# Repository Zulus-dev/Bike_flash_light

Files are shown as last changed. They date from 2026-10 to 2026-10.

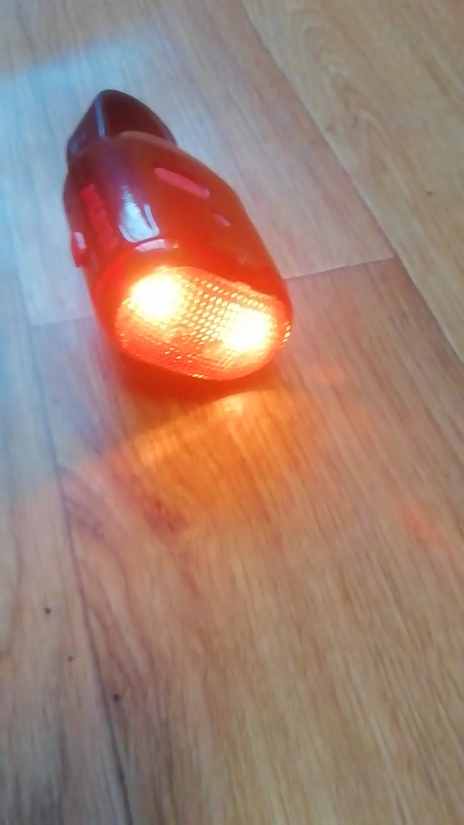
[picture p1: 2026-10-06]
images/VID_20261006_160003_exported_4752.jpg

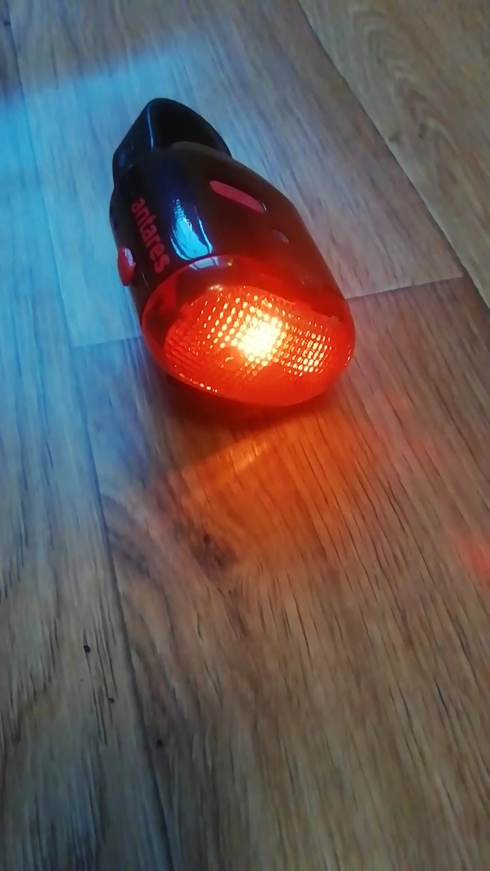
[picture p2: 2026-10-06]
images/VID_20261006_160003_exported_5719.jpg

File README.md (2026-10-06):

20261006_161844-COLLAGE
20261006_161900-ANIMATION
[Описание_веб_интерфейса_Bike_Light.md](https://github.com/user-attachments/files/33128371/_._._Bike_Light.md)

# Умный габарит-поворотник-стоп-сигнал для велосипеда  
**Полное техническое описание проекта (редакция 3.0)**

---

## 0. Инструменты разработки

| Инструмент | Назначение |
|---|---|
| **Blender** | 3D-моделирование корпуса / визуализация |
| **KiCad 9** | Схема и печатная плата |
| **VS Code + PlatformIO**| Прошивка (ESP-IDF framework) |

Сборка: PlatformIO, board `esp32-c3-devkitm-1`, framework `espidf`, flash 4 МБ, таблица разделов `partitions_ota.csv` (OTA).

---

## 1. Цель проекта

Создать устройство, которое:

- Работает от литиевого аккумулятора 18650 с BMS-платой, выдающей стабильные **+5 В**.
- Управляет каналами: **LED_LEFT**, **LED_CENTER**, **LED_RIGHT**, **LED_STRIP**, **LASER** + зуммер через **ULN2003A**.
- Мониторинг батареи (сглаженный) и **фоторезистор GL5528** в веб-UI.
- Функции: габарит (дыхание), стоп, поворотник, аварийка, охрана, автоаварийка, эффекты вкл/выкл.
- WiFi SoftAP для настройки, мониторинга и **OTA-обновления прошивки**.

---

## 2. Полный список компонентов

| Обозначение | Наименование | Параметры / корпус | Кол-во | Назначение |
|---|---|---|---|---|
| U1 | ESP32-C3 SuperMini | ESP32-C3FN4, 4 МБ Flash, USB-C | 1 | Контроллер |
| U2 | MPU-6050 (GY-521) | I2C, 3.3 В | 1 | Наклон и ускорение |
| U3 | ULN2003A | DIP-16 / SOIC-16 | 1 | Драйвер LED и зуммера |
| Q1 | AO3401A | P-MOSFET, SOT-23 | 1 | Ключ питания |
| Q2 | AO3400A | N-MOSFET, SOT-23 | 1 | POWER_HOLD |
| D1 | BMS 1S 5V | Защита + boost 5 В | 1 | Питание |
| D2…D6 | IR204A / LED | 3 мм | 5 | RIGHT, CENTER, LEFT, LASER, STRIP |
| R1–R5 | Резисторы | 120 Ом | 5 | Токоограничение LED/зуммера |
| R6 | Резистор | 100 кОм | 1 | Подтяжка G Q1 к +5 В |
| R7 | Резистор | 1 кОм | 1 | SW1 → G Q1 |
| R8 | Резистор | 100 кОм | 1 | Подтяжка G Q2 к GND |
| R9 | Резистор | 1 кОм | 1 | GPIO21 → G Q2 |
| R10, R11 | Резисторы | 100 кОм | 2 | Делитель батареи 1:2 |
| R12 | Резистор | 10 кОм | 1 | Делитель LDR |
| C2, C3, C6, C7 | Конденсаторы | 150 нФ | 4 | Развязка / фильтр АЦП |
| C8 | Конденсатор | 100 нФ | 1 | Фильтр LDR у GPIO0 |
| C4, C5 | Конденсаторы | 47 мкФ | 2 | Фильтр питания |
| SW1 | Кнопка | 6×6 мм | 1 | Включение питания |
| SW2 | Кнопка | 6×6 мм | 1 | Режимы / WiFi / выключение |
| BZ2 | Buzzer | 12×9.5 мм | 1 | Звук |
| BT1 | Аккумулятор | 18650 | 1 | Источник питания |
| LDR1 | GL5528 | Фоторезистор 5 мм | 1 | Освещённость |

---

## 3. Описание цепей и соединений

### 3.1. Силовая часть

- **BAT+** → вход BMS (BAT+).
- Выход BMS **5V+** → исток (S) Q1 (AO3401A).
- Затвор (G) Q1: R6 к 5V+, R7 к SW1 на GND, сток Q2.
- Сток (D) Q1 = шина **+5V**.
- Q2 (AO3400A): S → GND; G через R9 ← **GPIO21** (POWER_HOLD); R8 подтяжка G к GND.

### 3.2. Питание 3.3 В

Встроенный LDO ESP32-C3 SuperMini. **3V3** → MPU-6050 и делитель LDR (R12 + LDR1).

### 3.3. Светодиоды и зуммер (ULN2003A)

Аноды LED от +5V через 120 Ом; катоды на открытые коллекторы ULN.  
COM ULN → +5V, GND ULN → общая земля.

| Канал ULN | Вход | GPIO | Нагрузка |
|---|---|---|---|
| 1 | I1 | GPIO5 | Зуммер |
| 2 | I2 | GPIO4 | LED_RIGHT |
| 3 | I3 | GPIO3 | LED_CENTER |
| 4 | I4 | **GPIO2** | **LED_LEFT** (поворотник) |
| 5 | I5 | GPIO7 | LASER |
| 6 | I6 | **GPIO20**| **LED_STRIP** |
| 7 | I7 | — | не используется |

> LED_STRIP на **GPIO20** (не GPIO8). GPIO8 свободен — strapping для USB download.

### 3.4. Мониторинг батареи

```
BAT+ ── R11 100к ──●── GPIO1 (ADC1_CH1)
                   │
                  R10 100к
                   │
                  GND  +  C6 150нФ
```

Делитель 1:2. Замер раз в **3 с**, EMA + среднее за окно **~60 с** (UI без скачков от ШИМ/вибрации).

### 3.5. Фоторезистор GL5528

```
+3.3V ── R12 10к ──●── GPIO0 (ADC1_CH0)
                   │
                LDR1 GL5528
                   │
                  GND  +  C8 100нФ
```

Светло → `ldr_percent` → 0; темно → 100. Общий `ADC_UNIT_1` (`adc1_shared`) для батареи и LDR.

### 3.6. Кнопки и MPU-6050

- SW1 → через R7 на затвор Q1.
- SW2 → GPIO6.
- MPU-6050: SDA = GPIO9, SCL = GPIO10, AD0 = GND, VCC = 3V3.

### 3.7. Сводная таблица GPIO

| GPIO | Назначение | Примечание |
|---|---|---|
| GPIO0 | LDR (АЦП) | ADC1_CH0 |
| GPIO1 | Батарея (АЦП)| ADC1_CH1 |
| **GPIO2** | **LED_LEFT**  | Поворотник |
| GPIO3 | LED_CENTER | |
| GPIO4 | LED_RIGHT | |
| GPIO5 | BUZZER | |
| GPIO6 | BUTTON_MODE | |
| GPIO7 | LASER | |
| **GPIO8** | **свободен**  | Strapping — не нагружать ULN |
| GPIO9 | I2C_SDA | Strapping |
| GPIO10 | I2C_SCL | |
| **GPIO20**| **LED_STRIP** | |
| GPIO21 | POWER_HOLD | |

### 3.8. Прошивка по USB

Без снятия ULN (GPIO8 свободен).  
Принудительный download: BOOT (GPIO9) + RESET.

```bash
pio run -t upload
pio device monitor
```

### 3.9. OTA — обновление прошивки по Wi‑Fi

Таблица разделов: **`partitions_ota.csv`**

| Раздел | Размер (примерно) |
|---|---|
| ota_0 | ~1,75 МБ |
| ota_1 | ~1,75 МБ |

Типичный размер `firmware.bin`: **~0,9–1,2 МБ** — помещается в слот.

**Первый раз** после смены partition table — только USB. Дальше можно только по Wi‑Fi.

#### Где взять файл прошивки

После сборки:

```bash
pio run
```

Файл:

```
.pio/build/esp32c3_supermini/firmware.bin
```

Полный путь (Windows, пример):

```
C:\...\bike_light_esp_idf\.pio\build\esp32c3_supermini\firmware.bin
```

Нужен именно **`.bin`**, не `.elf`.

#### Как прошить по Wi‑Fi

1. Включить устройство, удержать **SW_MODE ≥ 8 с** → SoftAP.
2. Телефон/ПК: сеть **`BikeLight_AP`**, пароль **`12345678`**.
3. Браузер: **http://192.168.4.1**
4. Секция **WiFi** → видна версия прошивки → выбрать `firmware.bin` → **Загрузить прошивку**.
5. Дождаться 100 % и сообщения об OK — устройство **перезагрузится само**.

API: `POST /api/ota`, тело = сырой binary, `Content-Type: application/octet-stream`.

При обрыве загрузки boot остаётся на старом слоте (безопасный откат).

---

## 4. Принцип работы

- **Габарит** — дыхание LEFT / CENTER / RIGHT; лента и лазер по режимам и LDR.
- **Стоп** — динамическое ускорение (Δg по X/Y относительно медленной базы) + опционально наклон pitch; защита от кочек; подтверждение по времени.
- **Поворотник** — удержание бокового roll ≥ мин. угла; **приоритет над стопом** после старта; max по умолчанию 90°.
- **Аварийка / охрана / автоаварийка** — без изменений по смыслу.

### Стоп (параметры после полевых испытаний)

| Параметр | Поле config | Default | Смысл |
|---|---|---|---|
| Порог торможения | `brake_decel_threshold` | 0.45 g | Порог динамического Δg |
| Защита от кочек | `brake_bump_reject` | 5 (1–10) | Жёсткость отсева ударов |
| Подтверждение | `brake_confirm_sec` | 0.08 с | Сколько держать условие |
| Наклон (спуск) | `brake_pitch_deg` | 0 (выкл) | \|pitch\| ≥ порога; 0 = выкл |
| Длительность стопа | `brake_active_time_sec` | 1.5 с | Сколько мигать после события |

Алгоритм: `mag(filtered − slow_base)` по осям X/Y ≥ порога → candidate → confirm → стоп.  
Pitch-стоп **не** срабатывает при сильном боковом наклоне (не мешает поворотнику).

### Поворотник

| Параметр | Default |
|---|---|
| Мин. угол | 18° |
| Макс. угол | 90° |
| Удержание | 0.8 с |
| Время сигнала | 8 с |

Инверсия сторон — один раз (флаг `invert_turn_signals`), без двойного переворота в state machine.

### Режимы ленты / лазера

Без изменений: `strip_mode` (off / always / dark_only / scale), `laser_mode` (off / always / dark_only / brake_only_dark).

---

## 5. Кнопка SW_MODE

| Удержание | Действие |
|---|---|
| < 1 с | Обычный ↔ Аварийный |
| 2–4 с | Выключение питания |
| 4–8 с | Постановка / снятие охраны |
| ≥ 8 с | WiFi SoftAP вкл/выкл |

---

## 6. WiFi и веб-интерфейс

- SoftAP: `BikeLight_AP` / `12345678` → http://192.168.4.1  
- API: `/api/config`, `/api/status`, `/api/command`, **`/api/ota`**  
- Статус: режим, охрана, батарея (сглаженная), roll/pitch, LDR, **версия прошивки**  
- Секция WiFi: SSID, пароль, канал, таймаут, **загрузка OTA**  
- Секция Стоп: порог, мигание, длительность, яркость, **защита от кочек**, **подтверждение**, **наклон спуска**  
- NVS (`bike_config_t`); при смене размера структуры — defaults  

Подробности UI: `Описание_веб_интерфейса_Bike_Light.md` (в корне artifacts).

---

## 7. Архитектура прошивки

| Модуль | Назначение |
|---|---|
| adc1_shared | Один ADC_UNIT_1 |
| battery | АЦП 3 с, EMA, среднее ~60 с |
| ldr | percent, is_dark, гистерезис |
| config | NVS, defaults |
| led_control | ШИМ 5 каналов |
| buzzer | Тон, мелодии, сирена |
| motion_sensor | MPU-6050, LPF, Δg-тормоз, tilt |
| button | Антидребезг |
| state_machine | Режимы, приоритет поворот/стоп |
| effects | Вкл/выкл/охрана |
| wifi_web | SoftAP, HTTP, UI, **OTA** |
| main | Init, цикл ~50 Гц |

Пины в `config.h` (2.6): LED_LEFT=2, LED_STRIP=20, LASER=7, POWER_HOLD=21, LDR=0, BAT=1.

---

## 8. Инструкция пользователя

1. **Включение** — SW_POWER, эффект, габарит.  
2. **Езда** — дыхание; стоп и поворотники по датчику; лента/лазер по LDR.  
3. **Аварийка** — короткое SW_MODE.  
4. **Выключение** — 2–4 с.  
5. **Охрана** — 4–8 с.  
6. **Настройки / OTA** — ≥ 8 с, WiFi, браузер 192.168.4.1.

Рекомендуемые настройки после установки на раму (веб-UI → Сохранить):

| Параметр | Старт |
|---|---|
| Порог торможения | 0.35–0.50 |
| Подтверждение | 0.06–0.10 с |
| Защита от кочек | 4–6 |
| Мин. угол поворота | 15–20° |
| Макс. угол | 90° |
| Удержание поворота | 0.5–1.0 с |
| Наклон спуска | 0, пока не отладите |

---

## 9. Заключение (актуально на 2.6 + OTA)

- GPIO: LED_LEFT=2, LED_STRIP=20, GPIO8 свободен, POWER_HOLD=21.  
- Стоп: динамическое Δg, защита от кочек, confirm, опциональный pitch.  
- Поворотник: приоритет над стопом, hold ~0.8 с, max 90°.  
- Батарея: редкий замер + минутное среднее в UI.  
- **OTA по Wi‑Fi**: `partitions_ota.csv`, `POST /api/ota`, файл `.pio/build/esp32c3_supermini/firmware.bin`.  
- Стек: Blender, KiCad 9, VS Code + PlatformIO (ESP-IDF).

Устройство готово к сборке, прошивке (USB / OTA) и использованию.

[Описание_проекта_Bike_Light_v3.0.md](https://github.com/user-attachments/files/33128378/_._Bike_Light_v3.0.md)

# Веб-интерфейс Bike Light (ANTARES) — описание всех функций

**Редакция прошивки:** 3.0 (+ OTA, доработка стоп/поворот/батарея)  
**Точка доступа:** `BikeLight_AP` / `12345678`  
**Адрес:** http://192.168.4.1  
**Файл UI:** `bike_light_esp_idf/src/wifi_web.c`  
**Макет в проекте:** `imS7H.jpg` (концепт)

---

## 1. Общий вид и навигация

Заголовок: **ANTARES Bike Light**.

### Статус-бар (`/api/status`, ~0.8 с)

| Поле | Описание |
|---|---|
| Режим | NORMAL / HAZARD / ALARM |
| Охрана | `норма` / `охрана` / `ТРЕВОГА` |
| Батарея | % и вольты (**сглаженное среднее ~1 мин**, без скачков) |
| Roll / Pitch | Углы MPU-6050 |
| Acc | Суммарное ускорение |
| LDR | Темно/Светло, %, raw |
| Версия ПО | `fw_version` / `fw_date` (в секции WiFi) |

### Макеты (`ui_theme`)

| # | Имя | Поведение |
|---|-----|---|
| 0 | classic | Раскрывающиеся секции |
| 1 | hud | Карусель карточек |
| 2 | tiles | Сетка плиток (по умолчанию) |
| 3 | orbit | Иконки + панели |

### Стили иконок (`ui_icon_style`)

0 = soft · 1 = bold · 2 = duo (везде есть иконка LDR).

### API

| Метод | Путь | Назначение |
|---|---|---|
| GET | `/` | HTML |
| GET/POST | `/api/config` | Настройки ↔ NVS |
| GET | `/api/status` | Живой статус + версия прошивки |
| POST | `/api/command` | arm, disarm, calibrate, reboot, poweroff, melody_preview |
| **POST** | **`/api/ota`** | **Загрузка firmware.bin (сырое тело)** |

---

## 2. Секции настроек

### Управление (`ctrl`)

| Кнопка | Действие |
|---|---|
| На охрану / Снять | MODE_ALARM |
| Калибровка | MPU offsets → NVS |
| Ребут | `esp_restart` |
| Выключить | POWER_HOLD off |

### Габарит (`breath`)

Период дыхания, яркость крайних, яркость центра.

### Стоп (`brake`) — актуально после полевых испытаний

| Параметр | ID UI | Описание |
|---|---|---|
| Порог торможения | `brake` | Динамическое Δg (не сырой ax). Рекомендуется 0.35–0.50 |
| Период мигания | `bper` | |
| Длительность стопа | `bact` | Сколько мигать после события |
| Яркость стопа | `bbr` | |
| **Защита от кочек** | `bbump` | 1–10 (выше = жёстче отсев ударов) |
| **Подтверждение тормоза** | `bconf` | 0.04–0.40 с удержания условия |
| **Наклон вперёд (спуск)** | `bpitch` | 0–45°; **0 = выкл**. Срабатывает по \|pitch\| |

Стоп по pitch **не** активен при сильном боковом наклоне (чтобы не мешать поворотнику).

### Поворот (`turn`)

| Параметр | Рекомендация |
|---|---|
| Мин. угол | 15–20° |
| Макс. угол | **90°** (не ставить 60 — сильный наклон иначе «выключает» поворот) |
| Удержание | **0.5–1.0 с** |
| Время сигнала | 8 с |
| Инверсия сторон | если лево/право перепутаны |

После удержания наклона **поворотник имеет приоритет** над стопом.

### Авто / Охрана / LDR / Лазер / Лента / Эффекты / Звук

Без смены смысла относительно 2.6 (автоаварийка, пороги охраны, LDR, режимы laser/strip, мелодии).

### WiFi (`wifi`) + **OTA**

| Элемент | Описание |
|---|---|
| SSID / Пароль / Канал / Таймаут | Параметры SoftAP |
| **Версия прошивки** | Из `esp_app_get_description()` |
| **Файл .bin** | Выбор файла на телефоне/ПК |
| **Загрузить прошивку** | `POST /api/ota`, прогресс-бар |

---

## 3. Инструкция: прошивка по Wi‑Fi (OTA)

### 3.1. Получить файл прошивки на компьютере

В каталоге проекта PlatformIO:

```bash
pio run
```

Готовый файл:

```
bike_light_esp_idf/.pio/build/esp32c3_supermini/firmware.bin
```

Примеры полного пути:

- **Windows:** `C:\Users\<имя>\...\bike_light_esp_idf\.pio\build\esp32c3_supermini\firmware.bin`
- **Linux/macOS:** `.../bike_light_esp_idf/.pio/build/esp32c3_supermini/firmware.bin`

Только **`firmware.bin`**. Файлы `.elf` / `.map` для OTA не подходят.

Размер обычно **~0,9–1,2 МБ**; слот OTA ~1,75 МБ — запас есть.

Скопируйте `.bin` на телефон (облако, USB, мессенджер) или откройте UI с того же ПК, где лежит файл.

### 3.2. Первый раз после смены таблицы разделов

Если на плате ещё **не** была прошивка с `partitions_ota.csv`:

```bash
pio run -t upload
```

Только по **USB**. Дальше можно обновлять по Wi‑Fi.

### 3.3. Загрузка по Wi‑Fi

1. Питание устройства включено.  
2. Удержать **кнопку режимов ≥ 8 секунд** → SoftAP.  
3. Подключиться к Wi‑Fi **`BikeLight_AP`**, пароль **`12345678`**.  
4. Браузер: **http://192.168.4.1**  
5. Открыть секцию **WiFi**.  
6. Убедиться, что видна текущая **версия**.  
7. **Выбрать файл** → указать `firmware.bin`.  
8. Нажать **«Загрузить прошивку»**.  
9. Дождаться прогресса 100 % и «OK — перезагрузка…».  
10. Устройство перезапустится само; через ~10–20 с снова можно подключиться к AP (если SoftAP включите повторно).

Не выключайте питание и не отходите от AP во время загрузки.

### 3.4. Если OTA не прошла

- Проверьте, что файл именно `.bin` и размер > 50 КБ.  
- Перезапустите SoftAP (≥ 8 с).  
- При необходимости прошейте по USB: `pio run -t upload`.  
- При обрыве обычно остаётся **старая** рабочая прошивка (второй слот не активируется).

---

## 4. Связь с железом

- LDR GPIO0, батарея GPIO1, LED_LEFT GPIO2, LED_STRIP GPIO20, LASER GPIO7, POWER_HOLD GPIO21.  
- SoftAP только пока включён кнопкой (≥ 8 с) или из охраны.  
- Настройки → NVS; смена размера `bike_config_t` сбрасывает на defaults — после крупного обновления заново **Сохранить** нужные слайдеры.

---

## 5. Файлы в проекте

| Путь | Назначение |
|---|---|
| `Описание_веб_интерфейса_Bike_Light.md` | Этот документ |
| `bike_light_esp_idf/Описание_проекта_Bike_Light_v3.0.md` | Полное ТО проекта |
| `bike_light_esp_idf/src/wifi_web.c` | HTML + API + OTA |
| `bike_light_esp_idf/partitions_ota.csv` | Два OTA-слота |
| `.pio/build/esp32c3_supermini/firmware.bin` | Файл для USB и OTA (после `pio run`) |

---

*Соответствует прошивке 3.0 с OTA, динамическим стопом, приоритетом поворотника и сглаженной батареей.*

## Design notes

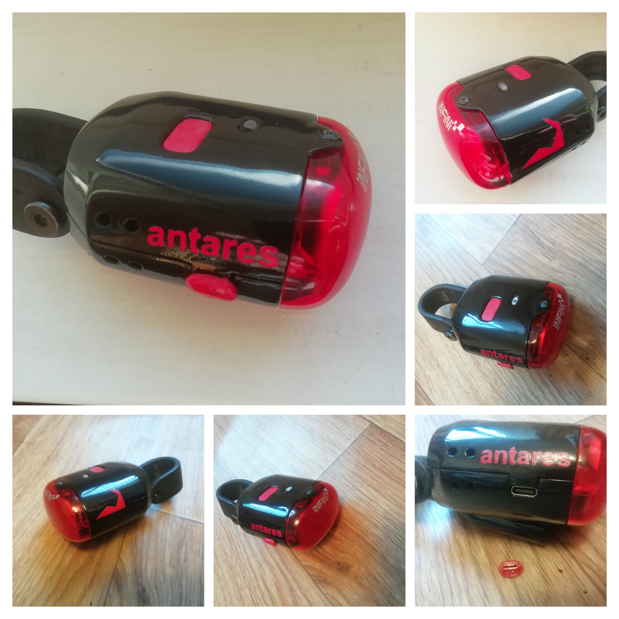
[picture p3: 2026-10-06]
images/20261006_161844-COLLAGE.jpg

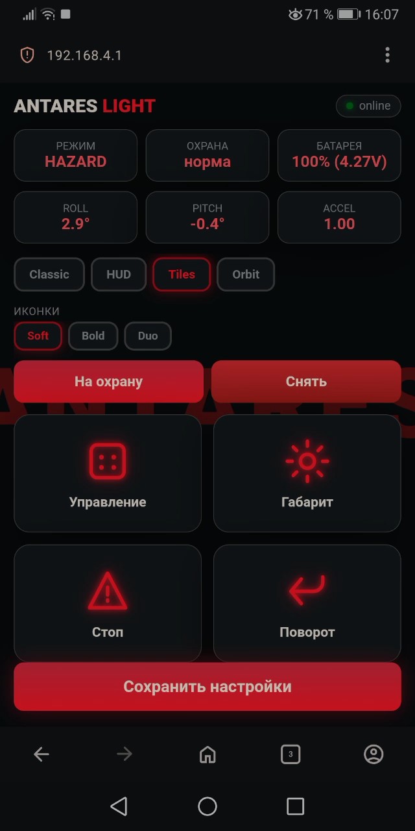
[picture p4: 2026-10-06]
images/SVID_20261006_160615_1_exported_90806.jpg

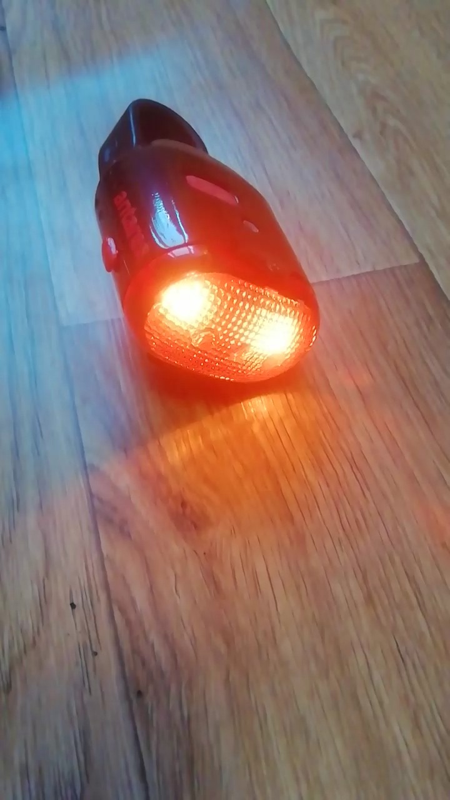
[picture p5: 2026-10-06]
images/VID_20261006_160003_exported_6387.jpg

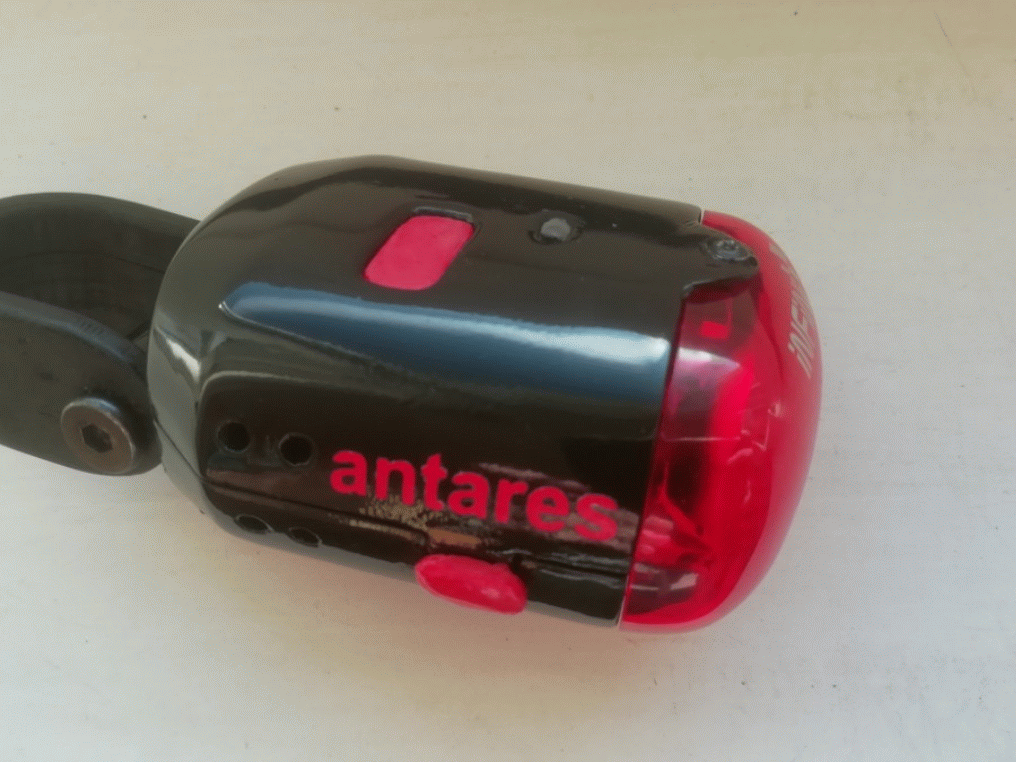
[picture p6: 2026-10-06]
images/20261006_161900-ANIMATION.gif

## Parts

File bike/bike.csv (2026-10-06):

Reference | Qty | Value | DNP | Exclude from BOM | Exclude from Board | Footprint | Datasheet
BT1 | 1 | Battery_Cell |  |  |  | Battery:BatteryHolder_MPD_BH-18650-PC | ~
BZ2 | 1 | Buzzer |  |  |  | Buzzer_Beeper:Buzzer_12x9.5RM7.6 | ~
C1,C2,C3 | 3 | 150nF |  |  |  | Capacitor_SMD:C_0805_2012Metric_Pad1.18x1.45mm_HandSolder | ~
C4,C5 | 2 | 10mF |  |  |  | Capacitor_THT:CP_Radial_D5.0mm_P2.00mm | ~
D1,D2,D3,D4,D5,D6 | 6 | IR204A |  |  |  | LED_THT:LED_D3.0mm_IRBlack | http://www.everlight.com/file/ProductFile/IR204-A.pdf
D7 | 1 | ~ |  |  |  | BMS_1S_5V:BMS_1S_5V
Q1 | 1 | AO3401A |  |  |  | Package_TO_SOT_SMD:SOT-23 | http://www.aosmd.com/pdfs/datasheet/AO3401A.pdf
Q2 | 1 | S9014 |  |  |  | Package_TO_SOT_THT:TO-92_Inline | http://www.unisonic.com.tw/datasheet/S8050.pdf
Q3,Q4,Q5,Q6 | 4 | S8050 |  |  |  | Package_TO_SOT_THT:TO-92_Inline | http://www.unisonic.com.tw/datasheet/S8050.pdf
R1,R2,R3 | 3 | 47 Om |  |  |  | Resistor_SMD:R_1206_3216Metric_Pad1.30x1.75mm_HandSolder | ~
R4,R5,R6,R7,R8,R9 | 6 | 1 kOm |  |  |  | Resistor_SMD:R_1206_3216Metric_Pad1.30x1.75mm_HandSolder | ~
R10 | 1 | 100 kOm |  |  |  | Resistor_SMD:R_1206_3216Metric_Pad1.30x1.75mm_HandSolder | ~
SW1 | 1 | SW_Power |  |  |  | Button_Switch_SMD:SW_SPST_Omron_B3FS-101xP | ~
SW2 | 1 | SW_mode |  |  |  | Button_Switch_SMD:SW_SPST_Omron_B3FS-101xP | ~
U1 | 1 | STM32F401CCUx |  |  |  | myelin-kicad:stm32f103c8t6-module-china | https://www.st.com/resource/en/datasheet/stm32f401cc.pdf
U2 | 1 | MPU-6050 |  |  |  | Sensor_Motion:InvenSense_QFN-24_4x4mm_P0.5mm | https://invensense.tdk.com/wp-content/uploads/2015/02/MPU-6000-Datasheet1.pdf
U3 | 1 | AMS1117-3.3 |  |  |  | Package_TO_SOT_SMD:SOT-223-3_TabPin2 | http://www.advanced-monolithic.com/pdf/ds1117.pdf

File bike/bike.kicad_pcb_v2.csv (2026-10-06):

Reference | Qty | Value | DNP | Exclude from BOM | Exclude from Board | Footprint | Datasheet
BT1 | 1 | Battery_Cell |  |  |  | Battery:Battery_Panasonic_CR1025-VSK_Vertical_CircularHoles | ~
BZ2 | 1 | Buzzer |  |  |  | Buzzer_Beeper:Buzzer_12x9.5RM7.6 | ~
C1,C2,C3,C6,C7 | 5 | 150nF |  |  |  | Capacitor_SMD:C_0805_2012Metric_Pad1.18x1.45mm_HandSolder | ~
C4 | 1 | 470 мкФ |  |  |  | Capacitor_THT:CP_Radial_D5.0mm_P2.00mm | ~
C5 | 1 | 47 mF |  |  |  | Capacitor_THT:CP_Radial_D5.0mm_P2.00mm | ~
D1 | 1 | ~ |  |  |  | BMS_1S_5V:BMS_1S_5V
D2 | 1 | IR204A_LED_RIGHT |  |  |  | LED_THT:LED_D3.0mm_IRBlack | http://www.everlight.com/file/ProductFile/IR204-A.pdf
D3 | 1 | IR204A_LED_CENTER |  |  |  | LED_THT:LED_D3.0mm_IRBlack | http://www.everlight.com/file/ProductFile/IR204-A.pdf
D4 | 1 | IR204A_LED_LEFT |  |  |  | LED_THT:LED_D3.0mm_IRBlack | http://www.everlight.com/file/ProductFile/IR204-A.pdf
D5 | 1 | IR204A_Laser |  |  |  | LED_THT:LED_D3.0mm_IRBlack | http://www.everlight.com/file/ProductFile/IR204-A.pdf
D6 | 1 | IR204A_Led_Strip |  |  |  | LED_THT:LED_D3.0mm_IRBlack | http://www.everlight.com/file/ProductFile/IR204-A.pdf
Q1 | 1 | AO3401A |  |  |  | Package_TO_SOT_SMD:SOT-23 | http://www.aosmd.com/pdfs/datasheet/AO3401A.pdf
Q2 | 1 | AO3400A |  |  |  | Package_TO_SOT_SMD:SOT-23_Handsoldering | http://www.aosmd.com/pdfs/datasheet/AO3400A.pdf
R1,R2,R3,R4,R5 | 5 | 100 Om |  |  |  | Resistor_SMD:R_1206_3216Metric_Pad1.30x1.75mm_HandSolder | ~
R6,R8,R10,R11 | 4 | 100 kOm |  |  |  | Resistor_SMD:R_1206_3216Metric_Pad1.30x1.75mm_HandSolder | ~
R7,R9 | 2 | 1 kOm |  |  |  | Resistor_SMD:R_1206_3216Metric_Pad1.30x1.75mm_HandSolder | ~
R12 | 1 | R_Photo |  |  |  | OptoDevice:R_LDR_4.9x4.2mm_P2.54mm_Vertical | ~
R13 | 1 | 10 кOm |  |  |  | Resistor_SMD:R_1206_3216Metric_Pad1.30x1.75mm_HandSolder | ~
SW1 | 1 | SW_Power |  |  |  | Button_Switch_SMD:SW_SPST_Omron_B3FS-101xP | ~
SW2 | 1 | SW_mode |  |  |  | Button_Switch_SMD:SW_SPST_Omron_B3FS-101xP | ~
U1 | 1 | ~ |  |  |  | ESP32-C3-SuperMini:ESP32-C3-SuperMini
U2 | 1 | OC09600 |  |  |  | OC09600:MODULE_OC09600
U3 | 1 | ULN2003A |  |  |  | Package_DIP:DIP-16_W7.62mm_LongPads | http://www.ti.com/lit/ds/symlink/uln2003a.pdf

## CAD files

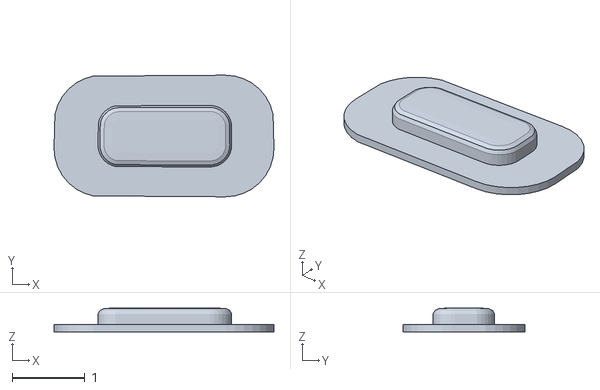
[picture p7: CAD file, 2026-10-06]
flash_box_cap_button.stl
3.03 x 1.68 x 0.327

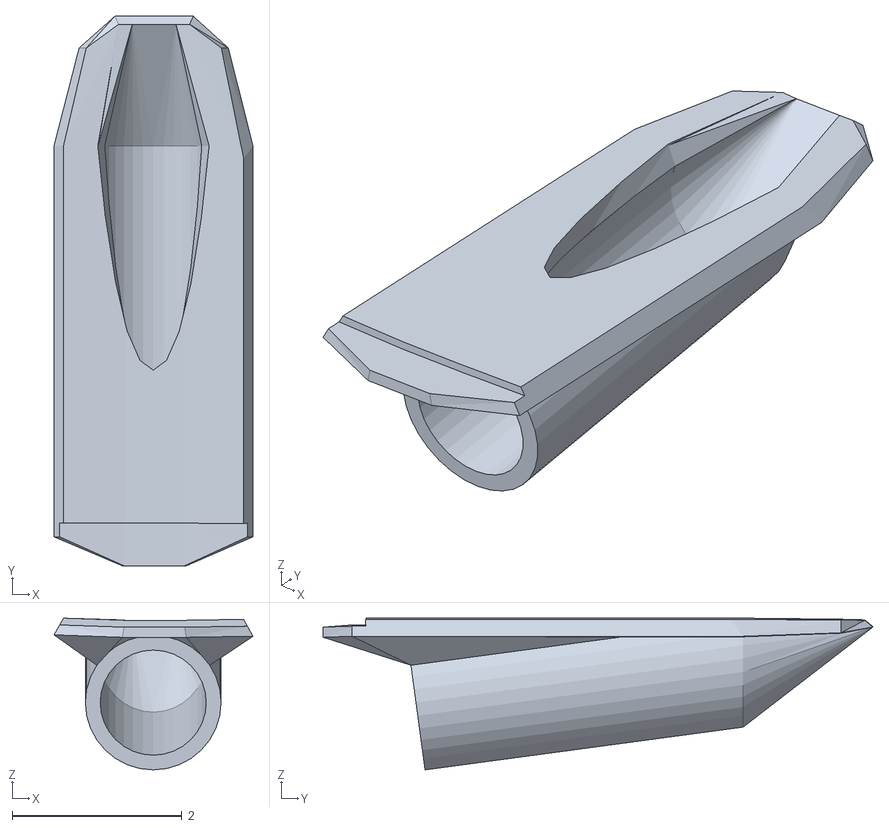
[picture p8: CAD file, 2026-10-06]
flash_box_laser.stl
2.35 x 6.48 x 1.79

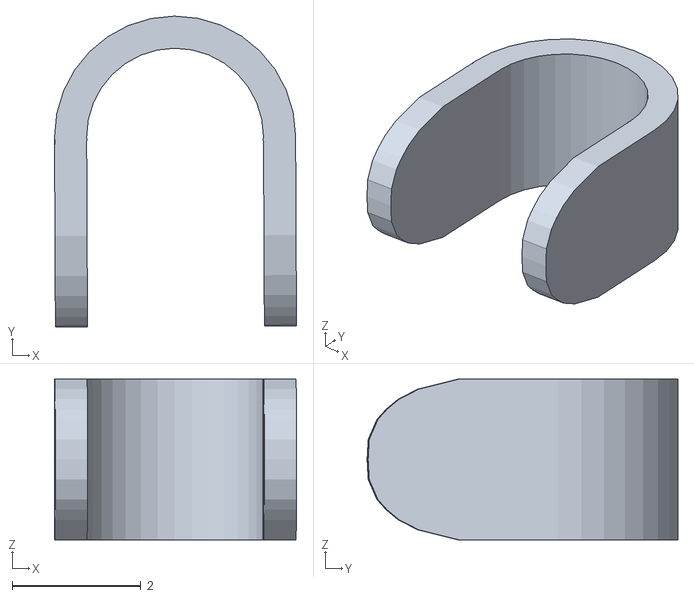
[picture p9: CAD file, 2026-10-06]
flash_box1.stl
3.76 x 4.83 x 2.50

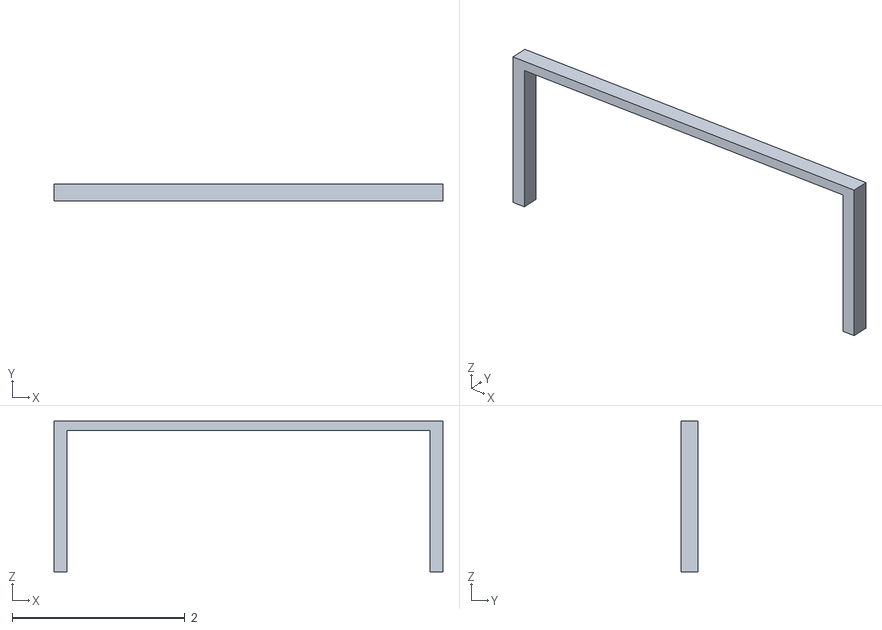
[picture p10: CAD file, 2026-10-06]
flash_box_mount.stl
4.50 x 0.2 x 1.75

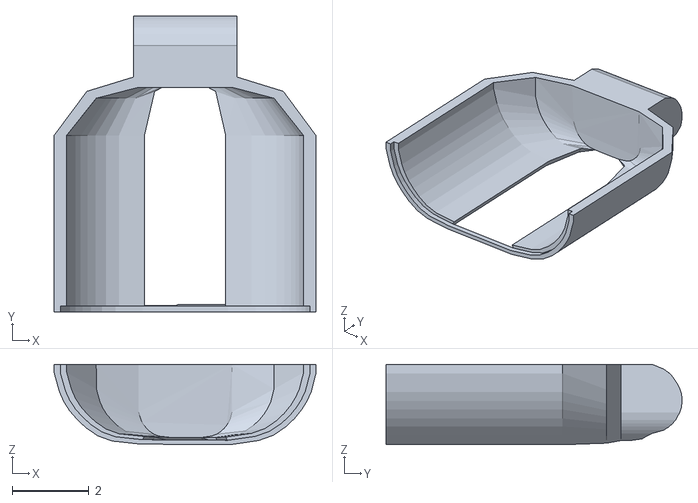
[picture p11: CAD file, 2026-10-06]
flash_box_down.stl
6.84 x 7.73 x 2.10

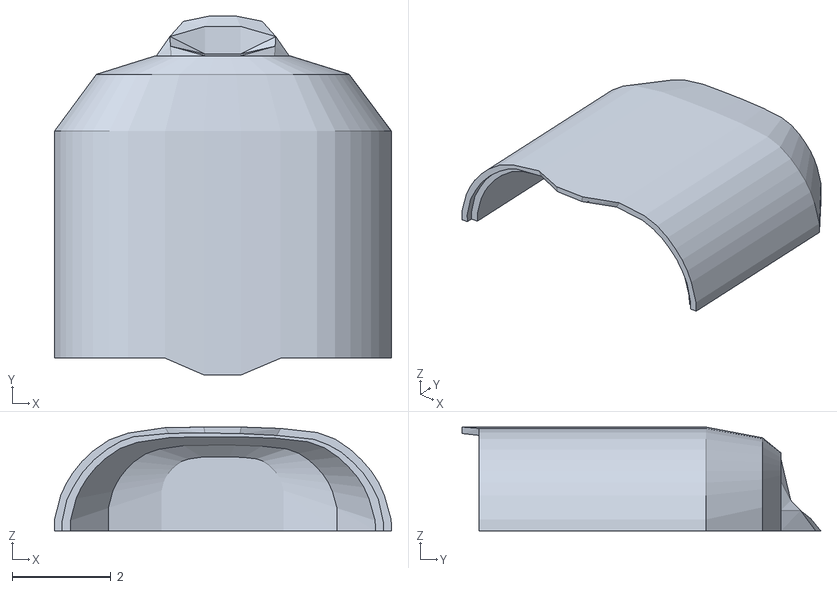
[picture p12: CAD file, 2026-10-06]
flash_box_up.stl
6.84 x 7.29 x 2.11

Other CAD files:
flash_box.blend

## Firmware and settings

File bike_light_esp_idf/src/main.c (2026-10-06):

/*
 * Умный габарит-поворотник-стоп-сигнал для велосипеда
 * Редакция 2.6 — чистый ESP-IDF + фоторезистор GL5528
 *
 * ESP32-C3 SuperMini + MPU6050 (SDA=GPIO9, SCL=GPIO10)
 * LED_LEFT = GPIO2, LED_STRIP = GPIO20 (GPIO8 свободен — strapping)
 * Laser (GPIO7 via ULN2003A) + Battery ADC (GPIO1)
 * LDR GL5528 (GPIO0 ADC) + POWER_HOLD (GPIO21)
 */

#include <stdio.h>
#include "freertos/FreeRTOS.h"
#include "freertos/task.h"
#include "esp_log.h"
#include "driver/gpio.h"
#include "nvs_flash.h"

#include "config.h"
#include "led_control.h"
#include "buzzer.h"
#include "motion_sensor.h"
#include "button.h"
#include "effects.h"
#include "state_machine.h"
#include "wifi_web.h"
#include "battery.h"
#include "ldr.h"

static const char *TAG = "MAIN";

/* Входы ULN в LOW до инициализации LEDC */
static void force_transistors_off(void)
{
    const int pins[] = {
        PIN_LED_LEFT,
        PIN_LED_CENTER,
        PIN_LED_RIGHT,
        PIN_LED_STRIP,
        PIN_BUZZER,
        PIN_LASER
    };

    for (size_t i = 0; i < sizeof(pins) / sizeof(pins[0]); i++) {
        gpio_config_t io = {
            .pin_bit_mask = (1ULL << pins[i]),
            .mode = GPIO_MODE_OUTPUT,
            .pull_up_en = GPIO_PULLUP_DISABLE,
            .pull_down_en = GPIO_PULLDOWN_DISABLE,
            .intr_type = GPIO_INTR_DISABLE
        };
        gpio_config(&io);
        gpio_set_level(pins[i], 0);
    }
}

static void power_hold_on(void)
{
    gpio_config_t io = {
        .pin_bit_mask = (1ULL << PIN_POWER_HOLD),
        .mode = GPIO_MODE_OUTPUT,
        .pull_up_en = GPIO_PULLUP_DISABLE,
        .pull_down_en = GPIO_PULLDOWN_DISABLE,
        .intr_type = GPIO_INTR_DISABLE
    };
    gpio_config(&io);
    gpio_set_level(PIN_POWER_HOLD, 1);
}

static void power_hold_off(void)
{
    // Сначала гасим все нагрузки
    force_transistors_off();
    gpio_set_level(PIN_POWER_HOLD, 0);
    vTaskDelay(pdMS_TO_TICKS(50));
}

static void main_task(void *arg)
{
    ESP_LOGI(TAG, "Main task started");

    while (1) {
        button_update();
        buzzer_update();
        wifi_web_update();
        battery_update();
        state_update();

                static bool was_power_off_fx = false;
        if (state_is_power_off_requested()) {
            if (effects_is_playing()) {
                was_power_off_fx = true;
            } else if (was_power_off_fx) {
                ESP_LOGW(TAG, "Powering off...");
                power_hold_off();
                while (1) {
                    vTaskDelay(pdMS_TO_TICKS(1000));
                }
            }
        }

        vTaskDelay(pdMS_TO_TICKS(20)); // ~50 Hz
    }
}

void app_main(void)
{
    force_transistors_off();
    power_hold_on();

    ESP_LOGI(TAG, "=== Bike Light v2.4 (ESP-IDF) starting ===");

        ESP_ERROR_CHECK(config_init());
    config_set_defaults();
    config_load();
    config_print();

        ESP_ERROR_CHECK(led_control_init());
    ESP_ERROR_CHECK(buzzer_init());
    ESP_ERROR_CHECK(button_init());
    ESP_ERROR_CHECK(motion_init());
    ESP_ERROR_CHECK(battery_init());
    ESP_ERROR_CHECK(ldr_init());
    effects_init();
    wifi_web_init();
    state_init();

        effects_start(EFFECT_POWER_ON);
    while (effects_is_playing()) {
        effects_update();
        buzzer_update();
        vTaskDelay(pdMS_TO_TICKS(15));
    }

        wifi_web_start_ap();

        xTaskCreate(main_task, "main_task", 12288, NULL, 5, NULL);

    ESP_LOGI(TAG, "=== Ready ===");
}

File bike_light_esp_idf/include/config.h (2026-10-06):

#pragma once

#include <stdint.h>
#include <stdbool.h>
#include "esp_err.h"

// ==================== ПИНЫ (редакция 2.6) ====================
// GPIO8 — strapping: для Joint Download Boot должен быть HIGH.
// Нагрузка через ULN на GPIO8 срывает USB-прошивку → LED_STRIP на GPIO20.
#define PIN_POWER_HOLD   21  /* удержание питания (Q2) */
#define PIN_BAT_ADC      1   /* ADC1_CH1 — делитель батареи */
#define PIN_LED_LEFT     2   /* ULN I4 — поворотник LEFT */
#define PIN_LED_CENTER   3
#define PIN_LED_RIGHT    4
#define PIN_BUZZER       5
#define PIN_BUTTON_MODE  6
#define PIN_LASER        7   /* ULN I5 */
#define PIN_LED_STRIP   20  /* ULN I6 — перенесён с GPIO8 (strapping) */
#define PIN_I2C_SDA      9
#define PIN_I2C_SCL     10
#define PIN_LDR          0   /* ADC1_CH0 — GL5528 */

// LEDC
#define LEDC_TIMER              LEDC_TIMER_0
#define LEDC_MODE               LEDC_LOW_SPEED_MODE
#define LEDC_DUTY_RES           LEDC_TIMER_8_BIT
#define LEDC_FREQUENCY          5000

#define LEDC_CHANNEL_LEFT       LEDC_CHANNEL_0
#define LEDC_CHANNEL_CENTER     LEDC_CHANNEL_1
#define LEDC_CHANNEL_RIGHT      LEDC_CHANNEL_2
#define LEDC_CHANNEL_STRIP      LEDC_CHANNEL_3
#define LEDC_CHANNEL_BUZZER     LEDC_CHANNEL_4
#define LEDC_CHANNEL_LASER      LEDC_CHANNEL_5

// ==================== РЕЖИМЫ ЛЕНТЫ И ЛАЗЕРА ====================
typedef enum {
    STRIP_MODE_OFF = 0,          /* полностью выключена */
    STRIP_MODE_ALWAYS,           /* всегда (игнорирует LDR) */
    STRIP_MODE_DARK_ONLY,        /* только когда темно */
    STRIP_MODE_SCALE             /* яркость масштабируется от освещённости */
} strip_mode_t;

typedef enum {
    LASER_MODE_OFF = 0,              /* полностью выключен */
    LASER_MODE_ALWAYS,               /* всегда (игнорирует LDR) */
    LASER_MODE_DARK_ONLY,            /* только когда темно */
    LASER_MODE_BRAKE_ONLY_DARK       /* только при торможении + только в темноте */
} laser_mode_t;

typedef enum {
    STRIP_EFFECT_BREATHING = 0,
    STRIP_EFFECT_SOLID,
    STRIP_EFFECT_HAZARD
} strip_effect_t;

// ==================== КОНФИГУРАЦИЯ ====================
typedef struct {
    // Габарит
    float breathing_period_sec;
    float side_max_brightness;      // 0-100
    float center_max_brightness;

    // Стоп
    float brake_decel_threshold;
    float brake_blink_period_sec;
    float brake_active_time_sec;
    float brake_brightness;           // 0-100 яркость стопа
    uint8_t brake_bump_reject;        // 1–10: защита от кочек (10 = макс. отсечение ложных)
    float brake_confirm_sec;          // сколько должен держаться тормоз, прежде чем сработать
    float brake_pitch_deg;            // наклон вперёд (°) для стопа на спуске; 0 = выкл

    // Поворотники
    float tilt_angle_min_deg;
    float tilt_angle_max_deg;
    float tilt_hold_time_sec;
    float turn_signal_active_sec;
    bool  invert_turn_signals;        // инверсия лево/право

    // Автоаварийка
    float stationary_time_sec;       // сек тишины → включить
    float movement_time_sec;         // сек движения → выключить
    uint8_t still_sensitivity;       // 1–10: насколько тихо, чтобы включить
    uint8_t move_sensitivity;        // 1–10: насколько заметно движение, чтобы выключить

    // Охрана
    float alarm_motion_threshold;
    float alarm_confirm_time_sec;
    float alarm_siren_duration_sec;

    // Эффекты
    int   power_effect_cycles;
    float power_effect_cycle_dur;
    int   arm_effect_cycles;
    float arm_effect_cycle_dur;

    // Звук (PC-speaker / магнитный)
    float    buzzer_volume;     /* 0–100 % */
    uint16_t buzzer_freq_hz;    /* частота тона 200–8000 */
    uint8_t  melody_power_on;   /* melody_id_t */
    uint8_t  melody_power_off;

    // ----- Фоторезистор (новый) -----
    bool     ldr_enable;            /* использовать фоторезистор */
    uint8_t  ldr_threshold;         /* порог «темно» 0–100 % (100 = полная темнота) */
    uint8_t  ldr_hysteresis;        /* гистерезис 0–30 % */

    // ----- Светодиодная лента (полная замена старых strip_*) -----
    uint8_t  strip_mode;            /* strip_mode_t */
    uint8_t  strip_effect;          /* strip_effect_t */
    uint8_t  strip_brightness_day;  /* 0–100, обычно 0 */
    uint8_t  strip_brightness_night;/* 0–100 */
    float    strip_period_sec;      /* период дыхания/мигания */

    // ----- Лазер (полная замена старых laser_*) -----
    uint8_t  laser_mode;            /* laser_mode_t */
    float    laser_brightness;      /* 0–100 */
    bool     laser_sync_brake;      /* мигать вместе со стоп-сигналом */

    // WiFi
    char  wifi_ap_ssid[32];
    char  wifi_ap_password[64];
    uint8_t wifi_ap_channel;
    uint8_t wifi_ap_max_clients;
    uint16_t wifi_idle_timeout_sec;

    // UI (только внешний вид веб-интерфейса, не влияет на логику фонаря)
    // 0=classic, 1=hud, 2=tiles, 3=orbit
    uint8_t ui_theme;
    // 0=soft (Neon Soft), 1=bold (Neon Bold), 2=duo (Neon Duo)
    uint8_t ui_icon_style;
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

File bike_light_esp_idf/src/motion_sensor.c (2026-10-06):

#include "motion_sensor.h"
#include "config.h"
#include "driver/i2c.h"
#include "esp_log.h"
#include "esp_timer.h"
#include "freertos/FreeRTOS.h"
#include "freertos/task.h"
#include <math.h>
#include <string.h>

static const char *TAG = "MPU";

#define I2C_PORT              I2C_NUM_0
#define MPU6050_ADDR          0x68
#define MPU6050_WHO_AM_I      0x75
#define MPU6050_PWR_MGMT_1    0x6B
#define MPU6050_ACCEL_XOUT_H  0x3B
#define MPU6050_CONFIG        0x1A
#define MPU6050_GYRO_CONFIG   0x1B
#define MPU6050_ACCEL_CONFIG  0x1C

static motion_data_t motion = {0};
static float filtered_roll = 0;
static float filtered_pitch = 0;
static int64_t last_update_us = 0;
static float ref_ax, ref_ay, ref_az;
static float ref_roll, ref_pitch;
static bool ref_saved;

/* LPF ускорений + ВЧ-оценка «кочки» */
static float filtered_ax = 0;
static float filtered_ay = 0;
static float ax_slow = 0;       /* очень медленная база для high-pass */
static float ay_slow = 0;
static float filtered_total = 1.0f;
static float bump_energy = 0;
static bool  filt_ax_init = false;

static esp_err_t mpu_write_reg(uint8_t reg, uint8_t val)
{
    uint8_t buf[2] = {reg, val};
    return i2c_master_write_to_device(I2C_PORT, MPU6050_ADDR, buf, 2, pdMS_TO_TICKS(100));
}

static esp_err_t mpu_read_regs(uint8_t reg, uint8_t *data, size_t len)
{
    return i2c_master_write_read_device(I2C_PORT, MPU6050_ADDR, &reg, 1, data, len, pdMS_TO_TICKS(100));
}

esp_err_t motion_init(void)
{
    i2c_config_t conf = {
        .mode = I2C_MODE_MASTER,
        .sda_io_num = PIN_I2C_SDA,
        .scl_io_num = PIN_I2C_SCL,
        .sda_pullup_en = GPIO_PULLUP_ENABLE,
        .scl_pullup_en = GPIO_PULLUP_ENABLE,
        .master.clk_speed = 400000,
    };
    ESP_ERROR_CHECK(i2c_param_config(I2C_PORT, &conf));
    ESP_ERROR_CHECK(i2c_driver_install(I2C_PORT, conf.mode, 0, 0, 0));

    // Проверка WHO_AM_I
    uint8_t who = 0;
    if (mpu_read_regs(MPU6050_WHO_AM_I, &who, 1) != ESP_OK ||
        (who != 0x68 && who != 0x70 && who != 0x98 && who != 0x71)) {
        ESP_LOGE(TAG, "MPU6050 not found (WHO_AM_I=0x%02X)", who);
        motion.valid = false;
        return ESP_FAIL;
    }

    // Пробуждение
    mpu_write_reg(MPU6050_PWR_MGMT_1, 0x00);
    vTaskDelay(pdMS_TO_TICKS(100));

    // DLPF ~21 Hz
    mpu_write_reg(MPU6050_CONFIG, 0x04);
    // Gyro ±500 dps
    mpu_write_reg(MPU6050_GYRO_CONFIG, 0x08);
    // Accel ±4g
    mpu_write_reg(MPU6050_ACCEL_CONFIG, 0x08);

    motion.valid = true;
    last_update_us = esp_timer_get_time();
    ESP_LOGI(TAG, "MPU6050 init OK (WHO=0x%02X)", who);
    return ESP_OK;
}

esp_err_t motion_update(void)
{
    if (!motion.valid) return ESP_FAIL;

    uint8_t raw[14];
    if (mpu_read_regs(MPU6050_ACCEL_XOUT_H, raw, 14) != ESP_OK) {
        return ESP_FAIL;
    }

    int16_t ax = (int16_t)((raw[0] << 8) | raw[1]);
    int16_t ay = (int16_t)((raw[2] << 8) | raw[3]);
    int16_t az = (int16_t)((raw[4] << 8) | raw[5]);
    int16_t gx = (int16_t)((raw[8] << 8) | raw[9]);
    int16_t gy = (int16_t)((raw[10] << 8) | raw[11]);
    int16_t gz = (int16_t)((raw[12] << 8) | raw[13]);

    // ±4g → 8192 LSB/g, ±500 dps → 65.5 LSB/(dps)
    motion.accel_x = (ax / 8192.0f) - g_config.accel_offset_x;
    motion.accel_y = (ay / 8192.0f) - g_config.accel_offset_y;
    motion.accel_z = (az / 8192.0f) - g_config.accel_offset_z;

    motion.gyro_x = (gx / 65.5f) - g_config.gyro_offset_x;
    motion.gyro_y = (gy / 65.5f) - g_config.gyro_offset_y;
    motion.gyro_z = (gz / 65.5f) - g_config.gyro_offset_z;

    motion.total_accel = sqrtf(motion.accel_x * motion.accel_x +
                               motion.accel_y * motion.accel_y +
                               motion.accel_z * motion.accel_z);

    float accel_roll  = atan2f(motion.accel_y, motion.accel_z) * 57.2957795f;
    float accel_pitch = atan2f(-motion.accel_x,
                               sqrtf(motion.accel_y * motion.accel_y +
                                     motion.accel_z * motion.accel_z)) * 57.2957795f;

    int64_t now = esp_timer_get_time();
    float dt = (now - last_update_us) / 1000000.0f;
    if (dt > 0.1f) dt = 0.01f;
    if (dt < 0.001f) dt = 0.001f;
    last_update_us = now;

    const float alpha = 0.96f;
    filtered_roll  = alpha * (filtered_roll  + motion.gyro_x * dt) + (1.0f - alpha) * accel_roll;
    filtered_pitch = alpha * (filtered_pitch + motion.gyro_y * dt) + (1.0f - alpha) * accel_pitch;

    motion.roll  = filtered_roll;
    motion.pitch = filtered_pitch;

    /* Умеренный LPF по осям + медленная база (high-pass для тормоза) */
    uint8_t br = g_config.brake_bump_reject;
    if (br < 1) br = 1;
    if (br > 10) br = 10;
    /* alpha: 0.40 … 0.75 — не глушим реальное торможение */
    float alpha_ax = 0.40f + (br - 1) * (0.35f / 9.0f);
    if (!filt_ax_init) {
        filtered_ax = motion.accel_x;
        filtered_ay = motion.accel_y;
        ax_slow = motion.accel_x;
        ay_slow = motion.accel_y;
        filtered_total = motion.total_accel;
        filt_ax_init = true;
    } else {
        filtered_ax = alpha_ax * filtered_ax + (1.0f - alpha_ax) * motion.accel_x;
        filtered_ay = alpha_ax * filtered_ay + (1.0f - alpha_ax) * motion.accel_y;
        /* Медленная база ~1–2 с — гравитационный «наклон» уходит в базу */
        ax_slow = 0.98f * ax_slow + 0.02f * motion.accel_x;
        ay_slow = 0.98f * ay_slow + 0.02f * motion.accel_y;
        filtered_total = 0.92f * filtered_total + 0.08f * motion.total_accel;
    }
    float high_freq = fabsf(motion.total_accel - filtered_total);
    bump_energy = 0.75f * bump_energy + 0.25f * high_freq;

    return ESP_OK;
}

const motion_data_t* motion_get_data(void)
{
    return &motion;
}

bool motion_is_braking(float threshold)
{
    if (threshold < 0.05f) threshold = 0.05f;

    /*
     * Динамическое ускорение = текущее − медленная база.
     * Наклон рамы (гравитация) уходит в базу и НЕ даёт ложный стоп.
     * Резкое торможение — всплеск на X или Y (ориентация модуля на раме разная).
     * Берём максимум |Δ| по горизонтальным осям.
     */
    float dx = filtered_ax - ax_slow;
    float dy = filtered_ay - ay_slow;
    float mag = fabsf(dx);
    if (fabsf(dy) > mag) mag = fabsf(dy);

    return (mag >= threshold);
}

bool motion_is_nose_down(float pitch_deg)
{
    if (pitch_deg <= 0.1f) return false;
    /* Срабатывает при наклоне вперёд ИЛИ назад (модуль может стоять зеркально) */
    return (fabsf(motion.pitch) >= pitch_deg);
}

bool motion_is_bump(float strength_g)
{
    if (strength_g < 0.05f) strength_g = 0.05f;
    return (bump_energy >= strength_g);
}

float motion_get_filtered_ax(void)
{
    return filtered_ax;
}
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

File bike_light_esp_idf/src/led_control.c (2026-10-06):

#include "led_control.h"
#include "config.h"
#include "driver/ledc.h"
#include "driver/gpio.h"
#include "esp_log.h"

static const char *TAG = "LED";

static float current_brightness[5] = {0};

static const ledc_channel_t channels[5] = {
    LEDC_CHANNEL_LEFT,
    LEDC_CHANNEL_CENTER,
    LEDC_CHANNEL_RIGHT,
    LEDC_CHANNEL_STRIP,
    LEDC_CHANNEL_LASER
};

static const int pins[5] = {
    PIN_LED_LEFT,
    PIN_LED_CENTER,
    PIN_LED_RIGHT,
    PIN_LED_STRIP,
    PIN_LASER
};

esp_err_t led_control_init(void)
{
    ledc_timer_config_t timer_cfg = {
        .speed_mode       = LEDC_MODE,
        .duty_resolution  = LEDC_DUTY_RES,
        .timer_num        = LEDC_TIMER,
        .freq_hz          = LEDC_FREQUENCY,
        .clk_cfg          = LEDC_AUTO_CLK
    };
    ESP_ERROR_CHECK(ledc_timer_config(&timer_cfg));

    for (int i = 0; i < 5; i++) {
        ledc_channel_config_t ch_cfg = {
            .gpio_num   = pins[i],
            .speed_mode = LEDC_MODE,
            .channel    = channels[i],
            .intr_type  = LEDC_INTR_DISABLE,
            .timer_sel  = LEDC_TIMER,
            .duty       = 0,
            .hpoint     = 0
        };
        ESP_ERROR_CHECK(ledc_channel_config(&ch_cfg));
    }

    ESP_LOGI(TAG, "LEDC initialized (LEFT/CENTER/RIGHT/STRIP/LASER)");
    return ESP_OK;
}

void led_set_brightness(led_group_t group, float percent)
{
    if (group > LED_GROUP_LASER) return;
    if (percent < 0.0f) percent = 0.0f;
    if (percent > 100.0f) percent = 100.0f;

    /* Оптимизация энергии: при 0 % жёстко держим duty = 0 (пин LOW) */
    current_brightness[group] = percent;
    uint32_t duty = (percent <= 0.01f) ? 0 : (uint32_t)(percent * 2.55f);
    ledc_set_duty(LEDC_MODE, channels[group], duty);
    ledc_update_duty(LEDC_MODE, channels[group]);
}

void led_set_all(float left, float center, float right)
{
    led_set_brightness(LED_GROUP_LEFT, left);
    led_set_brightness(LED_GROUP_CENTER, center);
    led_set_brightness(LED_GROUP_RIGHT, right);
}

void led_all_off(void)
{
    led_set_all(0, 0, 0);
    strip_off();
    laser_off();
}

void strip_set_brightness(float percent)
{
    led_set_brightness(LED_GROUP_STRIP, percent);
}

void strip_off(void)
{
    led_set_brightness(LED_GROUP_STRIP, 0);
}

void laser_set_brightness(float percent)
{
    led_set_brightness(LED_GROUP_LASER, percent);
}

void laser_off(void)
{
    led_set_brightness(LED_GROUP_LASER, 0);
}
